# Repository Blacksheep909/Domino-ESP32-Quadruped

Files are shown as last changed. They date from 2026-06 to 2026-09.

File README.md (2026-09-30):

# Domino ESP32 Composite Quadruped

Domino is a prototype ESP32 quadruped robot built around a carbon-and-printed composite chassis, a custom 3-DoF leg mechanism, CRSF/ExpressLRS radio control, PCA9685 servo output, and CAD-to-simulation experiments.

> Work in progress: Domino is an active engineering prototype, not a finished kit. The firmware, CAD exports, PCB package, calibration notes, and simulation files are included as a project record and technical reference. The repo does not yet contain a complete step-by-step build manual, measured BOM, wiring diagram, or validated production assembly process.

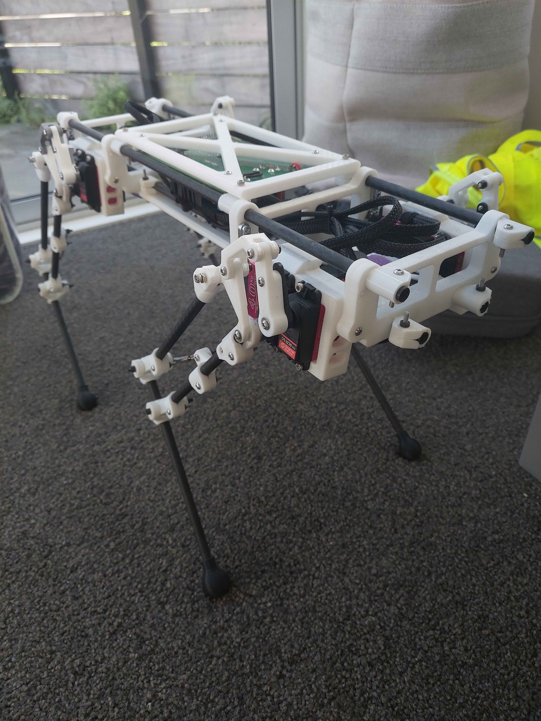
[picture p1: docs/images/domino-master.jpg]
Domino quadruped robot build


## Why This Project Matters

Domino is the successor to my earlier SpotMicro ESP32 Nitro work. The earlier project gave me a working base for servo-driven quadruped control, PCB packaging, and RC-controlled robot bring-up. Domino moves beyond that reference design into a more custom platform:

- A scratch-built mechanical layout using carbon members and 3D-printed structural parts.
- A serviceable electronics cage rather than a sealed body shell.
- Per-leg inverse kinematics for a custom 3-DoF mechanism.
- A move from iBUS-style receiver handling to custom CRSF/ExpressLRS parsing on the ESP32.
- A new Domino PCB manufacturing package based on lessons from the older SpotMicro Nitro board.
- CAD, STEP, USD, and Isaac Sim export work documenting the mechanical and simulation path.

As a portfolio project, Domino demonstrates mechanical design, embedded firmware, RC protocol work, power distribution, servo safety, calibration, and simulation constraints in one prototype hardware stack.

## Domino Quadruped Studio

**Quadruped Studio is the project's desktop engineering application.** Use it
to stand and move the CAD robot in simulation, develop gait profiles, inspect
joint travel, review calibration, record telemetry and plan routes.

**[Read the Studio guide](docs/quadruped-studio.md)** ·
**[Open the Studio source](https://github.com/Blacksheep909/Domino-ESP32-Quadruped/tree/codex/desktop-app/simulation/standalone)** ·
**[Download Studio 0.3.1 for Windows](https://github.com/Blacksheep909/Domino-ESP32-Quadruped/releases/tag/v0.3.1)**

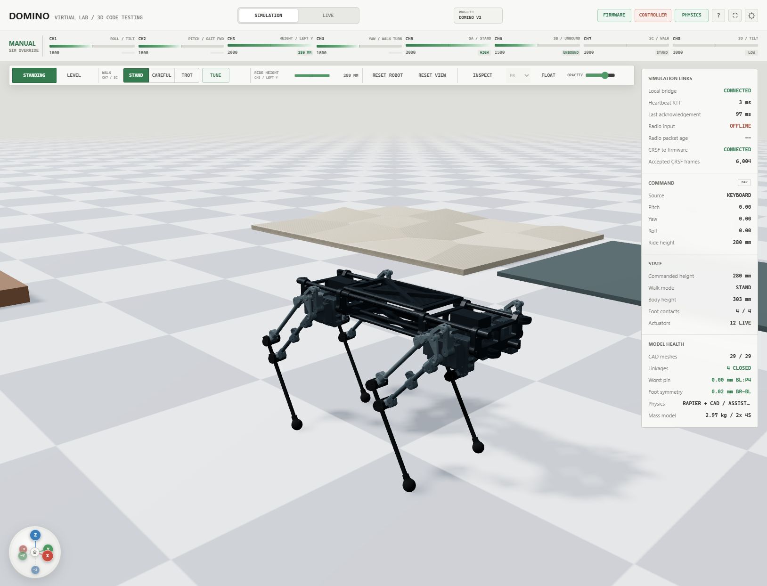
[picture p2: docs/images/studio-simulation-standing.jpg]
Domino standing on four feet in Quadruped Studio's Simulation workspace


*Captured from Studio 0.3.1. The robot is standing in the
local firmware/CAD simulation. The guide explains build availability and source
setup.*

- **Simulation:** firmware modes, actual CAD/linkage geometry, physics,
  keyboard/controllers, gait tuning and joint inspection.
- **LIVE:** comparison, data graphs, calibration, gait profiles, diagnostics
  and saved sessions through a compatible robot adapter.
- **Mission tools:** local route planning, geographic map overlays, GPS/LiDAR
  views and capability-gated vehicle controls.
- **Projects:** portable configuration files and telemetry capture/export.

## Current Status

Implemented or documented:

- [Domino Quadruped Studio](docs/quadruped-studio.md): Windows simulation and robot engineering application, with source on the `codex/desktop-app` branch.
- ESP32 DevKit firmware using PlatformIO and Arduino.
- PCA9685 output for twelve servos across four legs.
- CAD-derived inverse kinematics for hip, upper-leg, and lower-linkage angles.
- Custom CRSF/ExpressLRS receiver parser with packed-channel decoding, filtering, switch debouncing, and link-loss handling.
- Stand, stow, body tilt, ride-height preset, and experimental balance modes.
- MPU6050 IMU sampling and filtered roll/pitch state.
- Per-servo safety limits to reduce the chance of driving the mechanism into hard stops.
- STEP exports for assembly, body, and leg inspection.
- USD/USDZ exports from the Isaac Sim exploration path.
- Raw Isaac Lab URDF import smoke test documented for the generated CAD export.
- Domino PCB V1.1B Gerber package and PCB screenshots.

Still in progress:

- Full walking gait generation.
- Dynamic balance tuning.
- A complete measured BOM.
- Wiring diagrams and annotated cable-routing photos.
- Printed-part orientation, fastener, bearing, insert, and rod-length documentation.
- A validated start-to-finish public build manual.

## Where To Start

To use the desktop application, start with the [Quadruped Studio guide](docs/quadruped-studio.md).

If you are looking to build the physical robot start here:

1. [docs/control-notes.md](docs/control-notes.md) - coordinate frames, IK constants, servo mapping, and mode flow.
2. [docs/crsf.md](docs/crsf.md) - CRSF/ExpressLRS parser and receiver migration notes.
3. [docs/cad-design.md](docs/cad-design.md) - mechanical structure, STEP exports, composite cage, and simulation limitations.
4. [docs/electronics.md](docs/electronics.md) - electronics architecture, PCB evolution, and power/control notes.
5. [hardware/pcb/domino-quadruped-pcb-v1.1b](hardware/pcb/domino-quadruped-pcb-v1.1b) - Domino PCB V1.1B Gerber package.

## Mechanical Design

Each leg has three actuated degrees of freedom:

- Hip abduction/adduction.
- Upper-leg pitch.
- Lower linkage / knee motion.

The body uses a long central cage instead of a compact square chassis. This keeps wiring, receiver placement, PCB access, and servo harness routing serviceable while giving the leg modules room to move.

The lower leg behaves more like a closed-chain/four-bar mechanism than a simple open-chain robot arm. That creates useful packaging options, but it also makes firmware and simulation more demanding: servo mapping, linkage clearances, safe joint limits, and CAD-derived IK constants all need to agree.

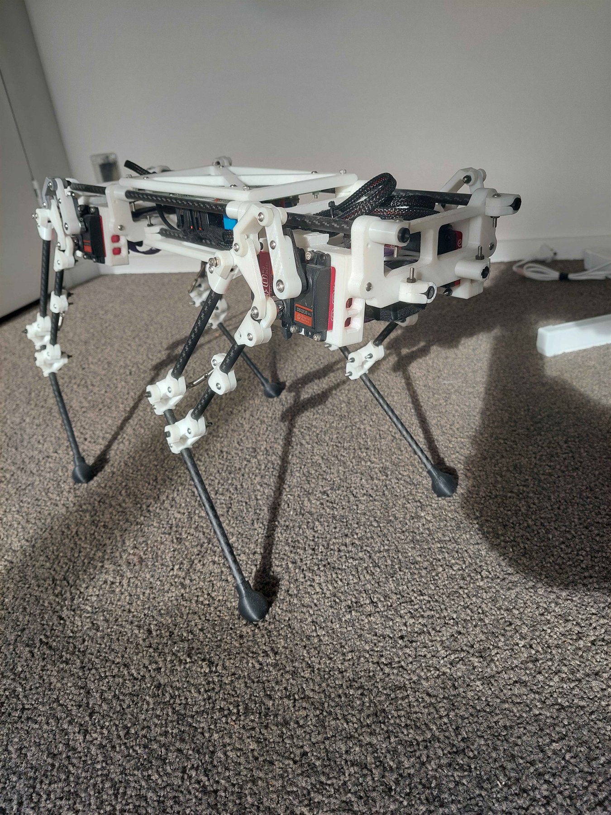
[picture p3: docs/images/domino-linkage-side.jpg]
Domino side linkage view


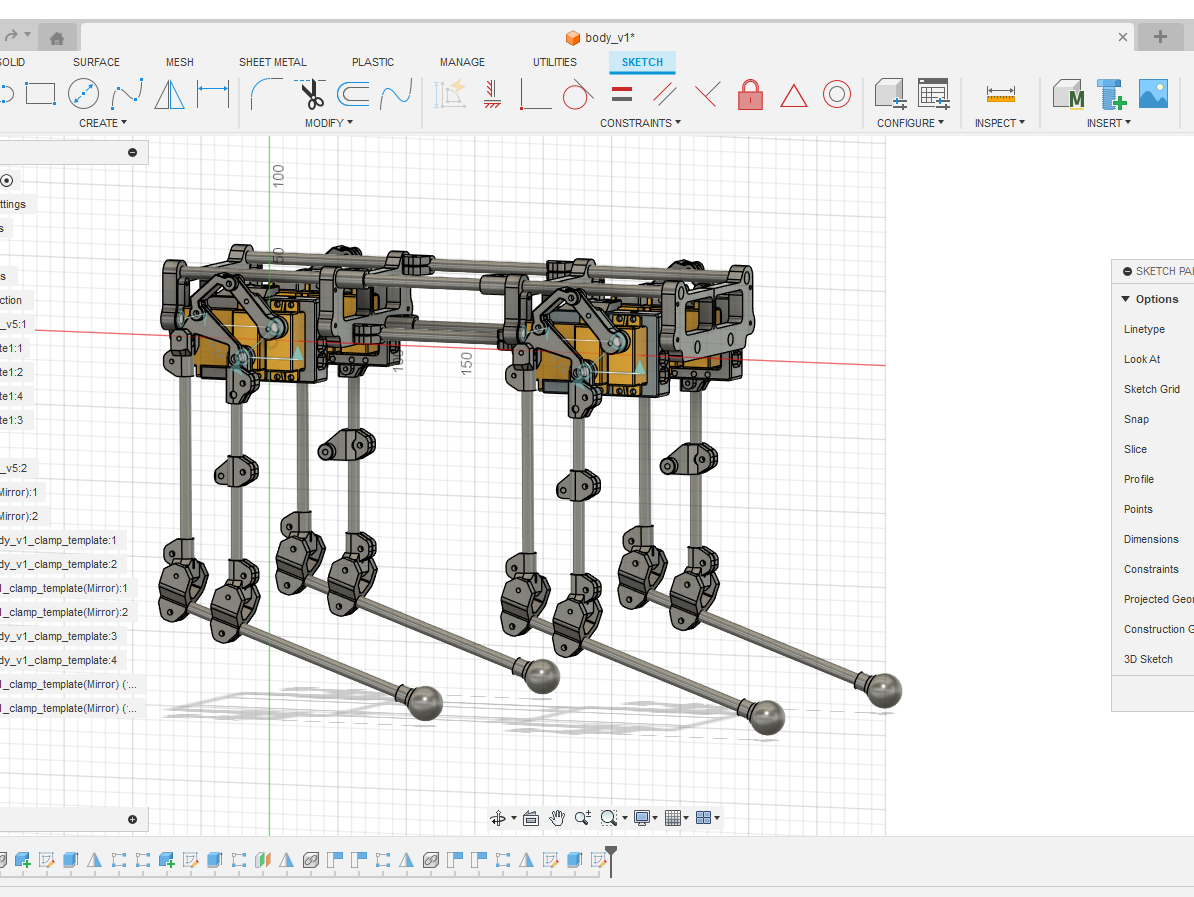
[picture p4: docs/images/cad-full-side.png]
CAD side view


The neutral CAD exports are included under [cad/step](cad/step). The mechanical write-up is in [docs/cad-design.md](docs/cad-design.md).

## Electronics

Domino began by reusing the electronics architecture from my SpotMicro ESP32 Nitro fork: ESP32 control, PCA9685 servo output, external servo power, receiver wiring, sensor headers, and utility connections gathered into a serviceable board layout.

The first Domino prototype reused the older PCB directly. Moving to CRSF/ExpressLRS did not require a full board redesign: the receiver needed suitable power, common ground, and its TX signal routed into the ESP32 serial input used by the firmware.

The newer Domino PCB V1.1B is a dedicated board package for this platform. It follows the same ESP32/PCA9685 quadruped-control concept, but adds extra headers, improves connector layout and silkscreen presentation, and addresses practical issues found while using the older board.

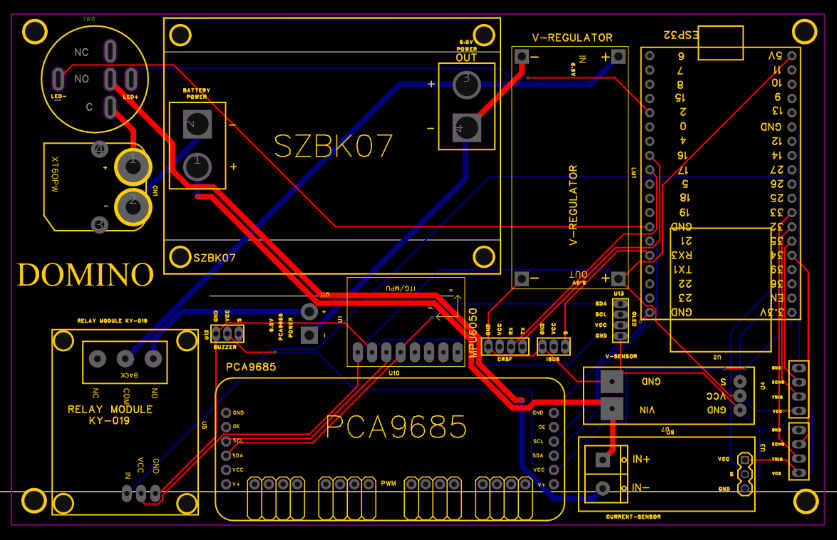
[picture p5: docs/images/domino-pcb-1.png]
Domino PCB V1.1B layout view


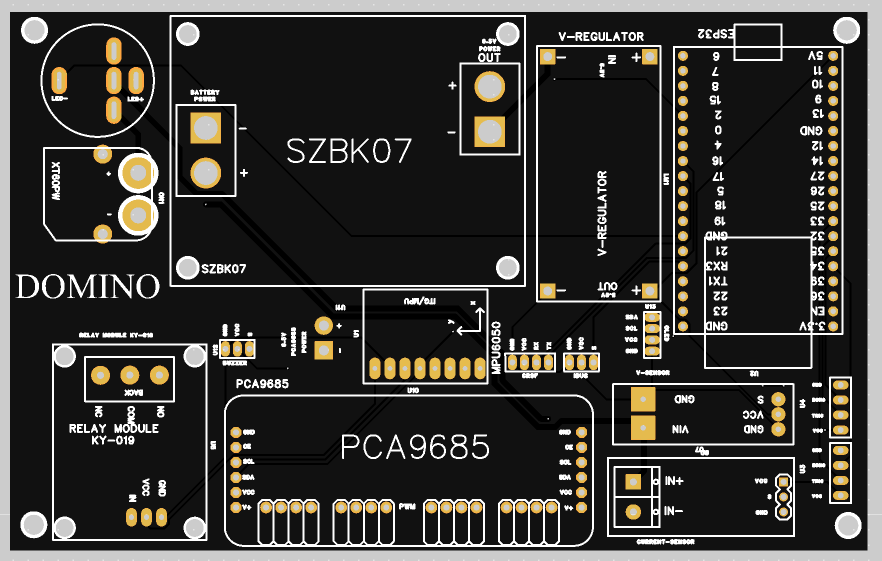
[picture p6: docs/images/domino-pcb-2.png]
Domino PCB V1.1B render


More detail is in [docs/electronics.md](docs/electronics.md).

## Firmware Architecture

The firmware is split by responsibility:

- `src/crsf.cpp` / `src/crsf.h`: CRSF frame parsing, channel unpacking, filtering, and link-health state.
- `src/ik.cpp` / `src/ik.h`: CAD-derived single-leg inverse kinematics.
- `src/leg_controller.cpp` / `src/leg_controller.h`: PCA9685 channel mapping, direction signs, trims, and servo limit enforcement.
- `src/imu.cpp` / `src/imu.h`: MPU6050 initialization, sampling, and filtered orientation state.
- `src/main.cpp`: high-level state machine, body pose model, ride height, tilt mode, balance experiment, and failsafe behavior.

High-level behavior generates body/foot pose targets, then passes them through the same IK and servo mapping path. That keeps stand, stow, tilt, balance, and future gait work tied to one low-level geometry model.

## CRSF / ExpressLRS Radio Link

One major goal of Domino was replacing simpler iBUS-style receiver handling with CRSF. CRSF is common in ExpressLRS systems and gives the robot a fast serial RC link, but it also requires correct frame synchronization, CRC validation, packed-channel decoding, filtering, and failsafe behavior.

The robot repo includes the integrated parser in `src/crsf.*` and a small example under [examples/crsf-esp32-reader](examples/crsf-esp32-reader). The reusable extraction now lives in its own repo:

- [Blacksheep909/ESP32_CRSF_Reader](https://github.com/Blacksheep909/ESP32_CRSF_Reader)

## CAD And Simulation Exports

The repo includes:

- STEP files under [cad/step](cad/step).
- USD/USDZ exports under [simulation/usd](simulation/usd).
- URDF reference export, Isaac topology report, and simulation bring-up notes under [simulation/isaac](simulation/isaac).
- CAD and simulation notes in [docs/cad-design.md](docs/cad-design.md) and [docs/simulation-notes.md](docs/simulation-notes.md).

The simulation work is exploratory. The visual model can be imported, but the real leg mechanism is closer to a closed-chain linkage than a URDF-friendly tree. A controllable simulation will need a simplified joint model or explicit constraints rather than a blind CAD import.

## Build And Bring-Up Status

The firmware can be built with PlatformIO:

```powershell
pio run
```

Upload to an ESP32 DevKit:

```powershell
pio run -t upload
```

Open the serial monitor:

```powershell
pio device monitor
```

Hardware bring-up should be done in layers: receiver first, then one servo, then one leg, then all legs on a stand. The current docs do not yet contain enough measured hardware detail to recommend building the full robot directly from the repo.

## Repository Layout

```text
.
|-- cad/
|   `-- step/                STEP exports for assembly, body, and leg modules
|-- hardware/
|   `-- pcb/                 Domino PCB Gerber package and notes
|-- simulation/
|   |-- isaac/               Isaac Sim / Isaac Lab bring-up notes and URDF topology tooling
|   |-- urdf/generated/      Generated URDF reference export
|   `-- usd/                 USD/USDZ exports for Isaac Sim experiments
|-- platformio.ini          PlatformIO build configuration
|-- src/                    Robot firmware
|-- examples/
|   `-- crsf-esp32-reader   Standalone CRSF parser demo
|-- docs/                   Design, calibration, electronics, and simulation notes
|-- include/                Project include directory
|-- lib/                    Project-local libraries
`-- test/                   Future firmware tests
```

## Related Work

This project builds on lessons from my earlier SpotMicro ESP32 fork:

- [Blacksheep909/SpotMicroESP32-Nitro-Fork](https://github.com/Blacksheep909/SpotMicroESP32-Nitro-Fork)

The earlier fork is closer to an instructional build log. Domino is a custom engineering snapshot: the firmware, CAD, PCB work, and simulation experiments are being shaped into a cleaner quadruped platform.

## Credits

Domino's mechanical direction is derived from the ESP32 quadruped robot design by [Tazer Technical](https://www.youtube.com/@TazerTechnical). Thanks to Tazer Technical for publishing the design ideas and build material that helped shape this project.

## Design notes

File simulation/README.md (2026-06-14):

# Simulation Exports

This folder contains USD-family exports from the Domino CAD-to-Isaac-Sim exploration.

> Work in progress: these files are reference exports, not a finished physics simulation. They are useful for visual import tests, scale checks, and future simulation model development.

## Files

| Path | Purpose |
| --- | --- |
| `isaac/` | Isaac Sim / Isaac Lab bring-up notes, URDF topology report, and validation tooling. |
| `urdf/generated/` | Generated URDF package from the CAD export. This is reference material, not a final training articulation. |
| `usd/Domino_Isaac_SIM.usd` | Lightweight Isaac Sim-oriented USD scene/export. |
| `usd/Domino_Quadruped.usd` | Domino quadruped USD export. |
| `usd/Domino_USD_Parts_Combined_Final.usdz` | Packaged combined USDZ export from the CAD-to-simulation trail. |

## Notes

- The visual geometry is useful.
- The generated URDF currently contains duplicate link names and loop-style child reuse, so it should not be treated as a finished Isaac articulation.
- A raw Isaac Lab URDF import smoke test has passed, but only as an import/build-artifact check. It is not a validated robot physics model.
- A clean one-leg prototype is included under `isaac/prototypes/one_leg` for the first controlled articulation tests.
- The joint hierarchy, physics properties, inertia, collisions, and actuation model still need dedicated simulation work.
- The closed-chain/four-bar leg linkage is the main reason a direct CAD import is not enough.

More context is in [../docs/simulation-notes.md](../docs/simulation-notes.md).

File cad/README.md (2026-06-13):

# CAD Exports

This folder contains neutral STEP exports for the current Domino prototype. They are included for inspection, measurement, adaptation, and CAD-to-simulation work.

> Work in progress: these are reference exports, not a complete manufacturing package. Validate clearances, servo fit, print tolerances, fastener sizes, and safe joint travel before building from them.

## STEP Files

| Path | Purpose |
| --- | --- |
| `step/assembly/Domino_URDF_Parts.step` | Full assembly-style STEP export for viewing the complete robot. |
| `step/combined/Domino_URDF_Parts_Combined.step` | Combined model export from the CAD-to-URDF trail. |
| `step/combined/Domino_URDF_Parts_Combined_Final.step` | Main combined reference export for the current documentation state. |
| `step/parts/Body.step` | Central body and electronics cage reference. |
| `step/parts/FL.step` | Front-left leg module. |
| `step/parts/FR.step` | Front-right leg module. |
| `step/parts/BL.step` | Back-left leg module. |
| `step/parts/BR.step` | Back-right leg module. |

Start with `step/combined/Domino_URDF_Parts_Combined_Final.step` to inspect the full robot. Use the individual leg files when checking mirrored geometry, servo orientation, linkage clearance, and horn travel.

More design context is in [../docs/cad-design.md](../docs/cad-design.md).

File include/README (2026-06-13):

Project-level public headers can be placed here if the firmware grows beyond the current `src/` module layout.

At the moment, Domino keeps its firmware headers beside their implementation files in `src/`:

- `src/crsf.h`
- `src/ik.h`
- `src/imu.h`
- `src/leg_controller.h`

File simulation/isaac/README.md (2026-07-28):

# Domino Isaac Sim / Isaac Lab Bring-Up

This folder is the working plan for turning Domino from CAD and firmware into a stable Isaac Sim / Isaac Lab robot. The aim is a trainable quadruped model, not just a pretty visual import.

> Current status: the raw CAD-generated URDF is not suitable as a training articulation by itself. The current Isaac Lab model reconstructs the mechanism as a stable 29-body passive-linkage system, starts in a captured bent neutral pose, exposes all 12 servo commands, and has a verified reference-conditioned four-foot linkage-swing controller. This is a mechanism demonstration, not an autonomous walking policy. Forward walking and terrain training are still in progress. The Isaac Sim and Isaac Lab runtimes are not included in this repository.

> Asset fidelity guardrail: the legacy `run_pin_linkage.py` modes are CAD-derived physics proxies with cube and sphere debug visuals. The newer CAD-linkage builder used by the policy-search and `DirectRLEnv` paths attaches the exported Domino STL link meshes to those moving physics bodies by default. Treat it as real Domino CAD visuals on simplified proxy physics, not as a final full-CAD collision model.

Visible, livestreamed, and camera-rendered proxy-only runs are blocked by default unless `--allow-proxy-visuals` is passed. This keeps the simplified cube/sphere debug scene from being mistaken for the actual Domino CAD visual model.

Visible, livestreamed, and camera-rendered multi-environment runs are also blocked by default in the CAD-linkage smoke, training, and playback scripts. Use `--num-envs 1` when checking whether the robot looks like Domino. Pass `--allow-multi-env-viewport` only when intentionally viewing cloned training batches.

## Reproduce the Current Baseline

Install Isaac Sim and Isaac Lab, then clone this repository. The CAD meshes, generated URDF package, 29-body linkage builder, 12-actuator environment, reference gait, reward configuration, launch scripts, and the pre-500-run `model_210` example policy are tracked. Isaac Sim, Isaac Lab, subsequent generated checkpoints, and local run logs are deliberately not committed.

Set the runtime locations if they are not installed at `C:\isaac-sim` and `C:\isaac-projects\IsaacLab`:

```powershell
$env:ISAAC_SIM_ROOT = "<path-to-Isaac-Sim>"
$env:ISAACLAB_ROOT = "<path-to-IsaacLab>"
```

Start a visible, single-environment PPO run using the actual Domino CAD meshes:

```powershell
powershell -ExecutionPolicy Bypass -File simulation/isaac/run-visible-domino-actual-cad-learning.ps1 `
  -NumEnvs 1 `
  -Iterations 100
```

Run 500 iterations headless across ten environments:

```powershell
powershell -ExecutionPolicy Bypass -File simulation/isaac/run-headless-domino-policy-training.ps1 `
  -NumEnvs 10 `
  -Iterations 500
```

The headless launcher resumes the newest compatible local checkpoint when one exists. Pass `-Fresh` to initialize a new actor from the tracked diagonal-trot reference, or pass `-ResumeCheckpoint <model.pt>` to choose a checkpoint explicitly. Checkpoints and reports are written below `simulation/isaac/out/`.

To train a policy from random network weights without a reference action in its observation, behavior cloning, or an imitation reward:

```powershell
powershell -ExecutionPolicy Bypass -File simulation/isaac/run-headless-domino-open-policy.ps1 `
  -NumEnvs 32 `
  -PolicyDevice cuda:0 `
  -PhysicsDevice cpu `
  -Iterations 500
```

This open-policy experiment still uses task-level reward shaping: a `0.10 m/s` forward command, measured forward displacement and velocity, diagonal stance/swing contact timing, swing-foot clearance, qualified liftoff-touchdown cycles, uprightness, and penalties for stagnation, wrong-way travel, lateral/yaw drift, contacting-foot slip, unequal completed air/contact times, abrupt actions, non-foot ground contact, and falls. The actor must discover the 12 servo commands itself; it is not given a scripted gait target. The launcher writes a checkpoint every ten iterations and applies a stricter single-policy walking gate after training.

The policy and physics devices are deliberately independent. Local July 2026 measurements on an RTX 3080 Ti found that this USD-synchronized closed-loop prototype trained faster with PPO on `cuda:0` and PhysX on `cpu`: four environments improved from `14.66` to `34.07` samples/s, ten improved from `16.98` to `48.47` samples/s, and sixteen CPU-physics environments reached `54.24` samples/s before the additional foot rewards were added. With contact slip, timing balance, and qualified-cycle rewards enabled, sixteen environments reached `50.84` samples/s and thirty-two reached `56.66` samples/s. Both device modes retained sub-`0.25 mm` maximum pin separation in the short comparison runs. The result is specific to this 29-body, 36-constraint prototype; conventional tensor-controlled tree articulations usually favor GPU PhysX.

Every new training report records `runtime.policy_device`, `runtime.physics_device`, `performance.ppo_training_wall_seconds`, and `performance.ppo_samples_per_second`. Re-run the same workload with `-PhysicsDevice cuda:0` when changing the linkage implementation, Isaac Sim version, or GPU driver rather than assuming the current result remains optimal.

The post-training gate also tracks confirmed contact-liftoff-swing-touchdown cycles per foot. A cycle is only valid when the foot remains airborne for multiple control steps, clears the terrain, travels relative to the body, returns with at least two-foot support, and stays within the configured body-tilt limit. Reports include per-foot cycle counts, rejected-cycle reasons, airborne fraction, clearance, travel, landing displacement, and single-foot domination. This rejects policies that produce large endpoint motion by throwing one leg or falling without demonstrating recoverable four-foot stepping.

Use the velocity-dominant V2 launcher for new locomotion training:

```powershell
powershell -ExecutionPolicy Bypass -File simulation/isaac/run-headless-domino-velocity-policy.ps1 `
  -NumEnvs 32 `
  -GateIterations 40 `
  -CorrectionIterations 80 `
  -TotalIterations 500
```

This launcher follows the task-first structure used by Isaac Lab's Go2, Anymal, and Spot velocity environments. Commanded velocity and directional progress dominate the locomotion reward, and stationary behavior under a nonzero command is explicitly penalized. A 40-iteration reference-scaffolded bootstrap first establishes coordinated linkage motion. The next 80 iterations emphasize measured positive-X travel while retaining a modest gait scaffold before the remaining training budget can start. Each gate also checks all-foot motion, all-linkage-drive motion, clearance, drift, tilt, resets, and pin-constraint separation. A failed gate stops the run rather than spending the full budget on a stationary or wrong-way policy. Use `run-headless-domino-open-policy.ps1` when reference actions must be completely absent.

The three gates deliberately become stricter rather than demanding a finished gait immediately. Stage one permits incomplete or unbalanced foot cycles while requiring safe motor exploration. Stage two requires at least one recoverable liftoff-touchdown cycle from every foot but tolerates an uneven early gait. The final stage requires a higher valid-cycle ratio and rejects single-foot domination.

Training episodes time out after `10 s`. A timeout is a normal state reset: PPO weights and optimizer state remain intact, and the policy continues learning from the next episode. The staged validation windows are `4.0 s`, `4.0 s`, and `4.8 s`, all shorter than the episode timeout, so a healthy policy is not rejected merely because it reached the configured time limit. Falls, unsafe body contact, excessive tilt, and missing foot recovery remain failures.

On the measured RTX 3080 Ti system, the default `32` environments and `24` control steps produce `768` transitions per PPO iteration. At `56.66` samples/s, a 500-iteration run contains `384,000` transitions and requires about `1 h 53 min` of PPO stepping. Allow roughly `2 h` total for the three CAD startups and policy gates. A from-scratch open policy may need `500-1500` iterations (`2-6 h`) before gait quality can be judged; checkpoint validation should determine when to stop, not wall-clock time alone.

On a fresh clone, the launcher automatically starts from `checkpoints/domino_actual_cad_baseline_model_210.pt`. To inspect that exact policy in a visible single-robot run before continuing PPO:

```powershell
powershell -ExecutionPolicy Bypass -File simulation/isaac/run-visible-domino-actual-cad-learning.ps1 `
  -NumEnvs 1 `
  -Iterations 1 `
  -ResumeCheckpoint simulation/isaac/checkpoints/domino_actual_cad_baseline_model_210.pt
```

This is still a work-in-progress locomotion experiment. The tracked setup demonstrates the real CAD appearance, all 12 servo channels, passive lower and upper linkage pins, reset/termination handling, and an active PPO training loop. It is not presented as a converged walking policy.

## Included Files

| Path | Purpose |
| --- | --- |
| `../usd/` | Existing USD/USDZ visual exports from the CAD-to-Isaac exploration. |
| `../urdf/generated/Domino_URDF_Parts_Combined_Final_description/` | Generated URDF package copied from the CAD export for reference and analysis. |
| `analyze-domino-urdf.ps1` | Repeatable URDF topology validator. |
| `analyze-domino-linkage-pivots.ps1` | Extracts named linkage pivot coordinates from the generated URDF for CAD-derived pin-joint tests. |
| `run-domino-urdf-import.ps1` | Parameterized Isaac Lab URDF import smoke-test helper. |
| `run-visible-domino-policy.ps1` | Visible actual-CAD playback launcher for the bent neutral pose and latest locally verified weight-transfer checkpoint. |
| `run-visible-domino-training.ps1` | Visible or headless BC/PPO launcher for the calibrated neutral, passive-linkage model. |
| `run-visible-domino-actual-cad-learning.ps1` | Current single-robot actual-CAD PPO configuration used for visual inspection. |
| `run-headless-domino-policy-training.ps1` | Clone-friendly 500-iteration headless launcher with automatic local checkpoint resume. |
| `run-headless-domino-open-policy.ps1` | From-scratch PPO launcher with no reference-action observation, behavior cloning, or imitation reward. |
| `run-headless-domino-velocity-policy.ps1` | Velocity-dominant, three-stage locomotion curriculum that rejects stationary or wrong-way policies before the long training stage. |
| `checkpoints/domino_actual_cad_baseline_model_210.pt` | Pre-500-run example policy used to reproduce or continue the current actual-CAD PPO experiment. |
| `prototypes/one_leg/` | Clean three-joint one-leg prototype for the first stable Isaac articulation. |
| `prototypes/actual_cad/` | USD audit/wrapper tools for the real Domino mesh CAD export. |
| `prototypes/pin_linkage/` | Minimal actuated pin-joint constraint prototype with generic and CAD-derived Domino linkage modes. |
| `prototypes/pin_linkage/run_domino_cad_linkage_one_foot_search.py` | Deterministic parallel search for stable single-foot unload commands using the current 12-actuator passive-linkage model. |
| `prototypes/pin_linkage/run_domino_cad_linkage_weight_transfer_search.py` | Searches stable full-body weight-transfer commands and verifies actual-CAD foot unloading for each leg. |
| `prototypes/pin_linkage/run_domino_cad_linkage_weight_transfer_cycle.py` | Runs the four verified commands as one continuous no-reset mechanics cycle. |
| `prototypes/pin_linkage/build_domino_weight_transfer_teacher.py` | Builds the tracked four-leg keyframe teacher after the continuous-cycle mechanics gate passes. |
| `config/domino_weight_transfer_cycle_teacher.json` | Current 1,360-step, 12-channel weight-transfer teacher used by BC and reference playback. |
| `prototypes/pin_linkage/run_domino_cad_linkage_teacher_order_search.py` | Evaluates all 24 four-leg swing orders in parallel against true endpoint, stability, and closure gates. |
| `prototypes/pin_linkage/build_domino_linkage_swing_teacher.py` | Builds the current verified 2,360-step linkage-swing teacher from four individually verified commands. |
| `config/domino_linkage_swing_cycle_teacher.json` | Current 12-channel teacher in rear-left, rear-right, front-right, front-left order. |
| `prototypes/pin_linkage/verify_domino_cad_linkage_reports.py` | Non-GPU verifier for local actual-CAD visual, 12-actuator, and playback report artifacts. |
| `prototypes/pin_linkage/plan_domino_cad_linkage_next_runs.py` | Generates staged PowerShell commands for the next CAD-linkage PPO/refinement experiments from verified baselines. |
| `prototypes/pin_linkage/compare_domino_cad_linkage_playbacks.py` | Compares a new CAD-linkage playback report against the retained forward, lateral-drift, and yaw baselines. |
| `reports/domino-urdf-topology.md` | Current topology report generated from the URDF export. |
| `reports/domino-linkage-pivots.md` | CAD-derived pivot report for the first lower-linkage loops. |
| `reports/domino-linkage-pivots.json` | Machine-readable pivot extraction output. |
| `reports/domino-urdf-import-smoke-test.md` | Result of the first Isaac Lab raw import smoke test. |
| `reports/domino-one-leg-import-smoke-test.md` | Result of the first clean one-leg import smoke test. |
| `reports/domino-one-leg-runtime-sweep.md` | Result of the first clean one-leg Isaac Lab articulation sweep. |
| `reports/domino-pin-linkage-runtime.md` | Results of the generic and CAD-derived actuated passive pin-linkage runtime tests. |
| `reports/domino-combined-linkage-characterization.md` | Motion characterization for the combined two-drive CAD-derived one-leg linkage. |
| `reports/domino-four-leg-linkage-runtime.md` | First all-leg CAD-derived pitch-linkage Isaac/PhysX smoke test. |
| `reports/domino-12-actuator-runtime.md` | First fixed-base all-leg scene exposing the full twelve-actuator Domino command layout. |
| `reports/domino-quadruped-runtime-sweep.md` | First clean all-leg 12-DoF Isaac Lab articulation runtime sweep. |
| `reports/domino-quadruped-contact-stand-env.md` | First floating-base contact smoke, first Domino stand `DirectRLEnv` smoke, first tiny RSL-RL PPO checkpoint smoke, and first playback smoke. |
| `reports/domino-policy-cad-linkage-contract.md` | Automated check that the clean policy action contract matches the CAD-derived shared fixed-body linkage report. |
| `reports/domino-floating-cad-linkage-contact.md` | First gravity/contact smoke for the floating CAD-derived twelve-actuator linkage scene. |
| `reports/domino-floating-cad-policy-reset.md` | First policy-style action and runtime reset smoke for the floating CAD-derived linkage scene. |
| `reports/domino-cad-linkage-direct-rl-env.md` | Isaac Lab `DirectRLEnv`, command-aware RSL-RL runs, signed-axis scripted gait search, 12-actuator BC/PPO warm starts, and current locomotion gap for the floating CAD-derived twelve-actuator linkage scene. |
| `reports/domino-split-linkage-servo-slew-status.md` | Historical split-closure and servo-slew milestone retained for engineering traceability. |

## Current Finding

The generated URDF is useful as a record of the CAD export, but it should not be imported blindly into Isaac as the final training model.

The current real visual source is `../usd/Domino_Quadruped.usd`. Direct USD inspection shows it opens as a mesh-based CAD visual export with 30 mesh prims, 0 rigid bodies, and 0 joints. That makes it useful for verifying the real Domino shape, scale, and CAD appearance, but it is not yet a trainable robot.

The raw-CAD identity audit writes to `out/cad_identity/domino_raw_cad_audit.json` and the meter-based wrapper writes to `out/cad_identity/domino_raw_cad_visual_wrapper.usda`. That wrapper is the clean visual-only file to open when checking the CAD identity before judging any physics or policy scene.

The current standalone policy-search scene is different from the raw visual export. It attaches 29 exported Domino STL meshes, totaling about 135k triangles, to 29 simplified moving physics bodies. The passive finite-link model includes both lower and upper two-pivot closure bodies instead of collapsing each loop into one joint. It reports 0 visible robot proxy cubes and 0 visible robot proxy spheres when CAD visuals are enabled, and the hidden proxy shapes are also marked as guide-purpose transparent geometry. That scene is useful for testing the twelve driven channels and closed-chain linkage behavior while showing the real Domino CAD geometry, but it should still be described as proxy physics rather than a final full-CAD collision model.

The local report verifier checks the current ignored JSON artifacts under `out/cad_identity/` before those artifacts are used as evidence. It verifies the actual-CAD visual audit, hidden proxy visuals, non-render proxy guard, 12 action channels, and the retained playback baselines. New PPO/refinement runs should also be checked with the playback comparison helper before replacing any retained baseline.

The current topology report shows:

- 37 link elements.
- 29 unique link names.
- 36 joint elements.
- 8 duplicate link-name groups.
- 8 child links with multiple incoming joints.
- 11 limited revolute joints and 25 continuous joints.

That means the file contains loop-style structure and repeated link names. Isaac/PhysX articulations need a tree structure for the articulation itself; loops can be closed separately using rigid-body joints between articulation links, but the core articulation still has to be authored cleanly. See the official PhysX articulation notes on tree structure and closing loops: [PhysX Articulations](https://nvidia-omniverse.github.io/PhysX/physx/5.4.1/docs/Articulations.html#articulation-tree-structure).

## Recommended Strategy

Do not try to make the exported CAD mates become the RL policy model directly. Build the simulator in layers:

1. **Visual model**
   - Use the USD exports for visual inspection, scale checks, orientation checks, and render/reference work.
   - Keep mesh collisions disabled or heavily simplified during early physics tests.

2. **Training articulation**
   - Create a clean 12-DoF tree articulation: hip ab/ad, upper-leg pitch, and lower/knee actuator coordinate for each leg.
   - Keep the action space tied to the twelve real servo commands rather than every passive CAD pin: four shoulder actuators plus two two-bar/four-bar linkage-drive actuators per leg.
   - Treat the upper linkage/pitch command as the second linkage-drive actuator for each leg, not as an extra passive pin or a separate reduced model.
   - Give every training joint a readable name before training; do not keep names like `Revolute 46` in the final model.

3. **Passive linkage fidelity**
   - First pass: treat the lower four-bar linkage as visual geometry attached to the controlled lower/knee body.
   - Second pass: add passive revolute pins and loop-closing rigid-body joints after a one-leg model is stable.
   - If the loop constraints fight the driven joints, keep the training model simplified and use the detailed linkage model only for validation.

4. **Isaac Lab asset config**
   - Spawn the final robot from USD using `ArticulationCfg` and `UsdFileCfg`.
   - Configure actuator groups for the twelve driven joints only.
   - Disable self-collision until basic falling, standing, and joint-limit tests are stable.
   - Use conservative solver settings and low drive gains during first motion tests.

5. **Policy path**
   - Validate one leg.
   - Validate all four legs standing on a raised fixture.
   - Train a stand/height-control task.
   - Keep velocity-command inputs explicit in the policy state, then add gait rewards and longer locomotion training after reset behavior, joint limits, and contacts are reliable.

## Commands

Run the URDF topology report:

```powershell
powershell -ExecutionPolicy Bypass -File simulation/isaac/analyze-domino-urdf.ps1
```

Run it against another exported URDF:

```powershell
powershell -ExecutionPolicy Bypass -File simulation/isaac/analyze-domino-urdf.ps1 -UrdfPath path\to\robot.urdf
```

Run a raw Isaac Lab import smoke test:

```powershell
powershell -ExecutionPolicy Bypass -File simulation/isaac/run-domino-urdf-import.ps1 `
  -IsaacLabRoot <path-to-IsaacLab> `
  -IsaacPython <path-to-isaac-python> `
  -OutputUsd <output-folder>/domino_raw_import.usd `
  -AcceptEula
```

The helper deliberately takes Isaac paths as arguments or environment variables. Do not hard-code personal workstation paths into this repository.

Run the clean one-leg prototype through the same importer:

```powershell
powershell -ExecutionPolicy Bypass -File simulation/isaac/run-domino-urdf-import.ps1 `
  -UrdfPath simulation/isaac/prototypes/one_leg/domino_one_leg_clean.urdf `
  -IsaacLabRoot <path-to-IsaacLab> `
  -IsaacPython <path-to-isaac-python> `
  -OutputUsd <output-folder>/domino_one_leg_clean.usd `
  -FixBase `
  -AcceptEula
```

Generate and import the clean all-leg quadruped prototype:

```powershell
<python> simulation/isaac/prototypes/quadruped/generate_quadruped_urdf.py

powershell -ExecutionPolicy Bypass -File simulation/isaac/run-domino-urdf-import.ps1 `
  -UrdfPath simulation/isaac/prototypes/quadruped/domino_quadruped_clean.urdf `
  -IsaacLabRoot <path-to-IsaacLab> `
  -IsaacPython <path-to-isaac-python> `
  -OutputUsd <output-folder>/domino_quadruped_clean.usd `
  -FixBase `
  -NoMergeJoints `
  -AcceptEula
```

Run the clean all-leg quadruped articulation sweep:

```powershell
<isaac-python> simulation/isaac/prototypes/quadruped/run_quadruped_sweep.py `
  --usd-path <output-folder>/domino_quadruped_clean.usd `
  --headless `
  --steps 600 `
  --report-path <output-folder>/domino_quadruped_sweep_report.json
```

Import the clean quadruped as a floating-base USD for gravity/contact tests:

```powershell
powershell -ExecutionPolicy Bypass -File simulation/isaac/run-domino-urdf-import.ps1 `
  -UrdfPath simulation/isaac/prototypes/quadruped/domino_quadruped_clean.urdf `
  -IsaacLabRoot <path-to-IsaacLab> `
  -IsaacPython <path-to-isaac-python> `
  -OutputUsd <output-folder>/domino_quadruped_clean_floating.usd `
  -NoMergeJoints `
  -AcceptEula
```

Run the floating-base gravity/contact smoke:

```powershell
<isaac-python> simulation/isaac/prototypes/quadruped/run_quadruped_contact_smoke.py `
  --usd-path <output-folder>/domino_quadruped_clean_floating.usd `
  --headless `
  --steps 1000 `
  --report-path <output-folder>/domino_quadruped_contact_report.json
```

Run the first stand-task `DirectRLEnv` smoke:

```powershell
<isaac-python> simulation/isaac/prototypes/quadruped/run_domino_stand_env_smoke.py `
  --usd-path <output-folder>/domino_quadruped_clean_floating.usd `
  --headless `
  --steps 300 `
  --num-envs 1 `
  --report-path <output-folder>/domino_stand_env_smoke_report.json
```

Run the first checkpoint-producing RSL-RL PPO smoke:

```powershell
<isaac-python> simulation/isaac/prototypes/quadruped/run_domino_stand_rsl_rl_train.py `
  --usd-path <output-folder>/domino_quadruped_clean_floating.usd `
  --headless `
  --num-envs 1 `
  --iterations 1 `
  --num-steps-per-env 8 `
  --log-root <output-folder>/domino_rsl_rl `
  --report-path <output-folder>/domino_stand_rsl_rl_report.json
```

Load and evaluate the newest RSL-RL checkpoint:

```powershell
<isaac-python> simulation/isaac/prototypes/quadruped/run_domino_stand_rsl_rl_play.py `
  --usd-path <output-folder>/domino_quadruped_clean_floating.usd `
  --headless `
  --num-envs 1 `
  --steps 250 `
  --log-root <output-folder>/domino_rsl_rl `
  --report-path <output-folder>/domino_stand_rsl_rl_play_report.json
```

Run a 16-env training-scale smoke after the one-env path is passing:

```powershell
<isaac-python> simulation/isaac/prototypes/quadruped/run_domino_stand_rsl_rl_train.py `
  --usd-path <output-folder>/domino_quadruped_clean_floating.usd `
  --headless `
  --num-envs 16 `
  --iterations 1 `
  --num-steps-per-env 8 `
  --log-root <output-folder>/domino_rsl_rl `
  --report-path <output-folder>/domino_stand_rsl_rl_train_16env_report.json
```

Extract CAD linkage pivots from the generated URDF:

```powershell
powershell -ExecutionPolicy Bypass -File simulation/isaac/analyze-domino-linkage-pivots.ps1
```

Run the CAD-derived one-joint lower-linkage test:

```powershell
<isaac-python> simulation/isaac/prototypes/pin_linkage/run_pin_linkage.py `
  --headless `
  --geometry domino-lower-triangle `
  --steps 600 `
  --drive-amplitude-deg 8 `
  --drive-frequency-hz 0.4 `
  --report-path <output-folder>/domino_lower_triangle_report.json `
  --save-usd <output-folder>/domino_lower_triangle.usd
```

Run the CAD-derived one-joint upper-linkage test:

```powershell
<isaac-python> simulation/isaac/prototypes/pin_linkage/run_pin_linkage.py `
  --headless `
  --geometry domino-upper-loop `
  --steps 600 `
  --drive-amplitude-deg 5 `
  --drive-frequency-hz 0.4 `
  --report-path <output-folder>/domino_upper_loop_report.json `
  --save-usd <output-folder>/domino_upper_loop.usd
```

Run the combined two-drive one-leg linkage test:

```powershell
<isaac-python> simulation/isaac/prototypes/pin_linkage/run_pin_linkage.py `
  --headless `
  --geometry domino-combined-leg `
  --steps 1000 `
  --fit-start-step 60 `
  --drive-amplitude-deg 2 `
  --secondary-drive-amplitude-deg 2 `
  --drive-frequency-hz 0.2 `
  --secondary-drive-frequency-hz 0.2 `
  --report-path <output-folder>/domino_combined_leg_report.json `
  --save-usd <output-folder>/domino_combined_leg.usd
```

Run the all-leg CAD-derived pitch-linkage test:

```powershell
<isaac-python> simulation/isaac/prototypes/pin_linkage/run_pin_linkage.py `
  --headless `
  --geometry domino-four-combined-legs `
  --steps 600 `
  --fit-start-step 60 `
  --drive-amplitude-deg 1 `
  --secondary-drive-amplitude-deg 1 `
  --drive-frequency-hz 0.15 `
  --secondary-drive-frequency-hz 0.15 `
  --report-path <output-folder>/domino_four_combined_legs_report.json `
  --save-usd <output-folder>/domino_four_combined_legs.usd
```

Run the all-leg independent drive calibration sweep:

```powershell
<isaac-python> simulation/isaac/prototypes/pin_linkage/run_pin_linkage.py `
  --headless `
  --geometry domino-four-combined-legs `
  --drive-schedule independent `
  --steps 3200 `
  --independent-segment-steps 400 `
  --independent-settle-steps 80 `
  --fit-start-step 0 `
  --drive-amplitude-deg 1 `
  --secondary-drive-amplitude-deg 1 `
  --drive-frequency-hz 0.15 `
  --secondary-drive-frequency-hz 0.15 `
  --report-path <output-folder>/domino_four_independent_calibration_report.json `
  --save-usd <output-folder>/domino_four_independent_calibration.usd
```

Run the fixed-base twelve-actuator scene:

```powershell
<isaac-python> simulation/isaac/prototypes/pin_linkage/run_pin_linkage.py `
  --headless `
  --geometry domino-four-12-actuators `
  --steps 600 `
  --fit-start-step 60 `
  --drive-amplitude-deg 1 `
  --secondary-drive-amplitude-deg 1 `
  --shoulder-drive-amplitude-deg 1 `
  --drive-frequency-hz 0.15 `
  --secondary-drive-frequency-hz 0.15 `
  --shoulder-drive-frequency-hz 0.15 `
  --report-path <output-folder>/domino_four_12_actuators_report.json `
  --no-print-report
```

Run the fixed-base twelve-actuator independent calibration sweep:

```powershell
<isaac-python> simulation/isaac/prototypes/pin_linkage/run_pin_linkage.py `
  --headless `
  --geometry domino-four-12-actuators `
  --drive-schedule independent `
  --steps 2400 `
  --independent-segment-steps 200 `
  --independent-settle-steps 40 `
  --fit-start-step 0 `
  --drive-amplitude-deg 1 `
  --secondary-drive-amplitude-deg 1 `
  --shoulder-drive-amplitude-deg 1 `
  --drive-frequency-hz 0.25 `
  --secondary-drive-frequency-hz 0.25 `
  --shoulder-drive-frequency-hz 0.25 `
  --report-path <output-folder>/domino_four_12_actuators_independent_report.json `
  --no-print-report
```

Run the shared-body fixed-base twelve-actuator independent calibration sweep:

```powershell
<isaac-python> simulation/isaac/prototypes/pin_linkage/run_pin_linkage.py `
  --headless `
  --geometry domino-four-12-fixed-body `
  --drive-schedule independent `
  --steps 1200 `
  --independent-segment-steps 100 `
  --independent-settle-steps 20 `
  --fit-start-step 0 `
  --drive-amplitude-deg 1 `
  --secondary-drive-amplitude-deg 1 `
  --shoulder-drive-amplitude-deg 1 `
  --drive-frequency-hz 0.5 `
  --secondary-drive-frequency-hz 0.5 `
  --shoulder-drive-frequency-hz 0.5 `
  --report-path <output-folder>/domino_four_12_fixed_body_independent_report.json `
  --no-print-report
```

Validate the policy action contract against a CAD-derived linkage JSON report:

```powershell
<python> simulation/isaac/prototypes/quadruped/check_cad_linkage_contract.py `
  --linkage-report <output-folder>/domino_four_12_fixed_body_independent_report.json `
  --urdf-path simulation/isaac/prototypes/quadruped/domino_quadruped_clean.urdf `
  --report-path <output-folder>/domino_policy_cad_contract_report.json
```

Run the floating CAD-derived twelve-actuator linkage contact smoke:

```powershell
<isaac-python> simulation/isaac/prototypes/pin_linkage/run_pin_linkage.py `
  --headless `
  --geometry domino-four-12-floating-body `
  --steps 300 `
  --drive-amplitude-deg 0 `
  --secondary-drive-amplitude-deg 0 `
  --shoulder-drive-amplitude-deg 0 `
  --drive-frequency-hz 0.5 `
  --secondary-drive-frequency-hz 0.5 `
  --shoulder-drive-frequency-hz 0.5 `
  --max-loop-closure-error-m 0.005 `
  --min-floating-root-height-m 0.02 `
  --report-path <output-folder>/domino_four_12_floating_body_report.json `
  --save-usd <output-folder>/domino_four_12_floating_body.usd `
  --no-print-report
```

Run the floating CAD-derived policy-style action/reset smoke:

```powershell
<isaac-python> simulation/isaac/prototypes/pin_linkage/run_pin_linkage.py `
  --headless `
  --geometry domino-four-12-floating-body `
  --drive-schedule policy-step `
  --steps 360 `
  --policy-action-scale-deg 0.25 `
  --policy-hold-steps 20 `
  --reset-interval-steps 120 `
  --max-post-reset-position-error-m 0.001 `
  --max-loop-closure-error-m 0.005 `
  --min-floating-root-height-m 0.02 `
  --report-path <output-folder>/domino_four_12_floating_policy_step_reset_report.json `
  --no-print-report
```

Run the floating CAD-linkage `DirectRLEnv` smoke:

```powershell
<isaac-python> simulation/isaac/prototypes/pin_linkage/run_domino_cad_linkage_env_smoke.py `
  --headless `
  --num-envs 4 `
  --steps 120 `
  --command-x-m-s 0.03 `
  --gait-frequency-hz 1.0 `
  --report-path <output-folder>/domino_cad_linkage_env_smoke_4env_command_report.json
```

Run a short command-aware RSL-RL training gate against the CAD-linkage env:

```powershell
<isaac-python> simulation/isaac/prototypes/pin_linkage/run_domino_cad_linkage_rsl_rl_train.py `
  --headless `
  --num-envs 4 `
  --iterations 10 `
  --num-steps-per-env 16 `
  --command-x-m-s 0.03 `
  --gait-frequency-hz 1.0 `
  --log-root <output-folder>/domino_rsl_rl `
  --report-path <output-folder>/domino_cad_linkage_rsl_rl_train_4env_command_10iter_report.json
```

Play back the newest CAD-linkage checkpoint:

```powershell
<isaac-python> simulation/isaac/prototypes/pin_linkage/run_domino_cad_linkage_rsl_rl_play.py `
  --headless `
  --num-envs 4 `
  --steps 240 `
  --command-x-m-s 0.03 `
  --gait-frequency-hz 1.0 `
  --log-root <output-folder>/domino_rsl_rl `
  --report-path <output-folder>/domino_cad_linkage_rsl_rl_play_4env_command_10iter_report.json
```

Verify the local actual-CAD and playback report artifacts without launching Isaac:

```powershell
<python> simulation/isaac/prototypes/pin_linkage/verify_domino_cad_linkage_reports.py
```

This verifier also checks that the top-level Isaac README, the detailed CAD-linkage DirectRLEnv report, and the actual-CAD audit report still contain the same current baseline numbers.

Generate the next recommended CAD-linkage policy experiment commands:

```powershell
<python> simulation/isaac/prototypes/pin_linkage/plan_domino_cad_linkage_next_runs.py
```

That planner was written for the pre-split-closure continuation path, so treat it as a command template rather than the current source of truth. For the current mechanics, continue from the stable `model_79.pt` / `35 deg` / `360 deg/s` servo-slew setup unless a new playback report proves a better checkpoint.

Compare a new playback report against the retained baselines:

```powershell
<python> simulation/isaac/prototypes/pin_linkage/compare_domino_cad_linkage_playbacks.py `
  --candidate <output-folder>/rsl_play_candidate.json `
  --json-summary <output-folder>/compare_candidate.json
```

## Isaac Runtime Notes

NVIDIA's current Isaac Lab import workflow recommends converting robot assets into USD and then writing an asset configuration for spawning and training. The Isaac Lab docs also call out useful URDF import settings such as fixed base selection, fixed-joint merging, joint drive configuration, and setting joint target type to `none` during import when you want to configure drives later. See:

- [Isaac Lab: Importing a New Asset](https://isaac-sim.github.io/IsaacLab/main/source/how-to/import_new_asset.html)
- [Isaac Lab: Writing an Asset Configuration](https://isaac-sim.github.io/IsaacLab/main/source/how-to/write_articulation_cfg.html)
- [Isaac Sim: Import URDF](https://docs.isaacsim.omniverse.nvidia.com/latest/importer_exporter/import_urdf.html)

## Immediate Next Milestone

This remains a work-in-progress simulation and policy-training project. The current baseline is a mechanically stable bring-up model, not a finished walking policy.

The current model uses:

- the exported Domino STL meshes for the visible robot;
- 29 simplified rigid physics bodies with passive finite lower and upper loop closures;
- all 12 real actuator channels: four 40 kg-cm shoulder servos and eight 35 kg-cm linkage servos;
- an authored 29-body neutral pose captured from a converged fixed-base linkage solve;
- CAD-derived visual-bottom foot contacts, explicit friction, realistic stall-torque caps, and a 90 deg/s target slew limit; and
- a 16-degree normalized action range around the bent neutral pose.

The current verified gates are:

| Gate | Result |
| --- | --- |
| Authored neutral, fixed base | Four bent legs, no straight-leg startup lock, approximately `1 micrometre` maximum pin error. |
| Zero-action free body, 10 seconds | No reset or detachment; about `7.2 deg` body tilt and `1.89 mm` maximum pin separation. |
| Independent 12-actuator sweep | Every actuator moves its own real CAD foot; minimum observed foot motion is about `29.5 mm`. |
| Settled free-body 12-actuator sweep | Every shoulder, lower, and upper channel moves under load in both directions with no termination; maximum pin separation stays below `3.1 mm` at the tested scale. |
| Four-leg order search | All 24 orders are evaluated in parallel. The selected rear-left, rear-right, front-right, front-left sequence was one of two orders that passed the stability, closure, drive-motion, and endpoint-motion gates. |
| Keyframed teacher playback | The 2,360-step reference completes with no reset or termination. True CAD-foot motion measured in each foot's own hip-carriage frame is `53.3-85.5 mm`; all eight linkage drives move `4.78-20.54 deg`. Maximum body tilt is `20.90 deg` and maximum pin separation is `3.73 mm`. |
| Reference-conditioned RSL-RL checkpoint | The 73-input, 12-output actor reproduces the appended verified target. Fresh checkpoint playback completes 2,360 steps with zero resets and the same endpoint, drive, tilt, and closure measurements as reference mode. A `0.0001` agreement snap executes the exact target when the policy is already within tolerance, avoiding contact-chaos divergence from floating-point copy error. |
| Visible actual-CAD inspection | A slowed single-robot playback shows the real Domino CAD, four attached bent legs, driven lower and upper links changing angle, passive closure bars remaining closed, and every foot endpoint moving. No proxy robot geometry is visible. |

The teacher and reference-conditioned checkpoint prove that the real CAD visuals, 12-channel action contract, bent neutral startup, servo limits, and closed-linkage physics run together. They do not prove autonomous locomotion learning. The current controller deliberately follows a verified mechanism trajectory; the next policy must learn stable residuals or an independent gait that produces controlled forward velocity.

Launch the current visible checkpoint:

```powershell
$env:ISAAC_SIM_ROOT = "<path-to-Isaac-Sim>"
$env:ISAACLAB_ROOT = "<path-to-IsaacLab>"
powershell -ExecutionPolicy Bypass -File simulation/isaac/run-visible-domino-policy.ps1 `
  -VisibleStartDelayS 8 `
  -VisibleStepDelayS 0.04 `
  -NoHoldOpen
```

Set `ISAAC_SIM_ROOT` and `ISAACLAB_ROOT`, or pass `-IsaacSimRoot` and `-IsaacLabRoot`. Automatic checkpoint selection accepts only the current hip-frame training artifact when either its embedded validation or a matching fresh-process validation report passed. It does not fall back to historical checkpoints. The delay options make the 47.2-second control sequence easier to inspect in the viewport.

Re-run the continuous mechanics gate and rebuild the tracked teacher after changing any of the four promoted command files:

```powershell
<isaac-python> simulation/isaac/prototypes/pin_linkage/run_domino_cad_linkage_weight_transfer_cycle.py `
  --headless `
  --leg-order 1,3,0,2 `
  --report-path simulation/isaac/out/cad_identity/next_policy/weight_transfer_context_verified_four_foot_cycle_v2.json `
  --no-print-report

<python> simulation/isaac/prototypes/pin_linkage/build_domino_weight_transfer_teacher.py
```

The builder refuses to publish a teacher unless the source continuous-cycle report passed its global mechanics gate.

Run the current lower-linkage visibility diagnostic:

```powershell
powershell -ExecutionPolicy Bypass -File simulation/isaac/run-visible-domino-policy.ps1 `
  -PolicyMode fixed `
  -TerrainType flat `
  -ActionScaleDeg 8 `
  -FixedActions "0,1,-1,0,0,0,0,0,0,0,0,0"
```

This is a mechanical one-foot unload probe, not a learned policy. It starts with the same zero-action neutral settle used by policy playback.

Run the current actual-CAD PPO experiment:

```powershell
powershell -ExecutionPolicy Bypass -File simulation/isaac/run-visible-domino-actual-cad-learning.ps1 `
  -NumEnvs 1 `
  -Iterations 100
```

The next policy pass should focus on:

- Preserve the authored neutral pose, zero-action hold, all-12-actuator sweep, and joint-separation gates.
- Turn the verified four-foot unloading sequence into an overlapping stance/swing gait with positive forward progress.
- Train velocity tracking on flat ground before introducing stairs or rough terrain.
- Keep stance/swing labels tied to settled foot trajectories so initial gravity settlement does not count as gait motion.
- Retain per-foot clearance, slip, lateral-drift, yaw, body-height, tilt, and loop-closure gates during PPO refinement.
- Keep verifying all 12 actuator channels: four shoulder hip ab/ad drives, four lower-linkage drives, and four upper pitch/linkage drives.
- Keep the detailed closed-linkage model as the mechanical validation authority, even if policy iteration later moves to a simpler tree articulation.

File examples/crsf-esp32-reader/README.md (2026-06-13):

# ESP32 CRSF Reader Example

This PlatformIO example reads CRSF / ExpressLRS RC channel frames on an ESP32 without running the full Domino robot firmware.

Use it when bringing up a receiver or checking channel mappings before connecting servos.

## Hardware

- ESP32 DevKit.
- CRSF / ExpressLRS receiver.
- Receiver TX wired to ESP32 RX pin 16.
- Common ground between receiver and ESP32.

The example initializes `Serial2` at 420000 baud and prints decoded channel values to the USB serial monitor at 115200 baud.

## Build

```powershell
pio run
```

## Monitor

```powershell
pio device monitor
```

The reusable standalone version is published here:

- [Blacksheep909/ESP32_CRSF_Reader](https://github.com/Blacksheep909/ESP32_CRSF_Reader)

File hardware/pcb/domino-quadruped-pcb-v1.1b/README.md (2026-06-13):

# Domino Quadruped PCB V1.1B

This folder contains the Gerber manufacturing package for the Domino Quadruped PCB V1.1B.

> Work in progress: this is a prototype hardware package. Inspect the Gerbers and confirm the connector pinout, power path, and mounting requirements before ordering or assembling the board.

## Files

| Path | Purpose |
| --- | --- |
| `gerbers/Gerber_Domino_Quadruped_PC_V1.1B_2026-06-13.zip` | Gerber/drill package for PCB manufacturing. |

The package contains copper layers, solder mask, silkscreen, board outline, drill files, a document layer, flying probe data, and a short ordering note.

## Design Context

This board builds on the SpotMicro ESP32 Nitro quadruped PCB concept: an ESP32-based controller board that consolidates servo control, receiver wiring, sensor connections, and power/control headers.

Domino V1.1B moves that idea toward a cleaner robot-specific board:

- Extra headers for expansion, bring-up, and receiver wiring.
- Continued ESP32/PCA9685 control architecture.
- Cleaner connector placement and silkscreen presentation.
- Better fit for the Domino electronics cage.
- Fixes for practical issues found while testing with the older board.

Domino PCB V1.1B layout view

Domino PCB V1.1B render

## Bring-Up Notes

Before installing the PCB in the robot:

1. Inspect the Gerbers in a PCB viewer.
2. Confirm board outline and mounting holes against the electronics cage.
3. Confirm receiver power, ground, and CRSF signal routing.
4. Power logic and servo rails carefully.
5. Test one servo channel before connecting all twelve servos.

See [../../../docs/electronics.md](../../../docs/electronics.md) for broader electronics notes.

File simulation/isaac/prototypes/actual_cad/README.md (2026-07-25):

# Domino Actual CAD USD Checks

This folder is for checking the real Domino CAD export separately from the simplified Isaac physics prototypes.

Use `simulation/usd/Domino_Quadruped.usd` as the current visual source of truth. It is a mesh-based USD export from the Domino CAD package. It is not an articulated Isaac Lab robot yet: it has mesh visuals, but no rigid bodies, joints, actuators, or policy-ready contact model.

Do not use the standalone pin-linkage proxy screenshots as portfolio evidence of the final robot geometry. The older pin-linkage scene uses CAD-derived pivot coordinates, but its visible bodies are cubes and foot spheres. The current CAD-linkage audit path attaches the Domino STL link package and rejects the scene if the expected `29` link meshes, `135508` visible triangles, or hidden-proxy checks do not pass.

## Audit

Run the audit with a Python that can import `pxr`:

```powershell
$env:ISAAC_SIM_ROOT = "<isaac-sim-root>"
<python> simulation/isaac/prototypes/actual_cad/domino_actual_cad_usd.py `
  --cad-usd simulation/usd/Domino_Quadruped.usd `
  --write-wrapper `
  --output-usd <output-folder>/domino_actual_cad_visual.usda `
  --json-report <output-folder>/domino_actual_cad_audit.json
```

The wrapper is visual-only. It references the real CAD USD and applies a 0.001 scale into a meter-based stage for Isaac viewing. It is intended for visual verification before the mesh is attached to the training articulation.

## Current Asset Status

| Asset | Status |
| --- | --- |
| `simulation/usd/Domino_Quadruped.usd` | Real mesh CAD visual export; opens as 30 mesh prims, 0 rigid bodies, and 0 joints. |
| `cad/step/combined/Domino_URDF_Parts_Combined_Final.step` | Combined CAD reference export for geometry inspection and re-export. |
| `simulation/urdf/generated/Domino_URDF_Parts_Combined_Final_description/` | Generated URDF/STL export with named links and pivots; useful for topology and linkage mapping. |
| `simulation/isaac/out/cad_floating/domino_four_12_floating_body.usd` | Older generated proxy physics scene; cube/sphere visuals and PhysX revolute constraints. |
| `simulation/isaac/prototypes/pin_linkage/audit_domino_cad_linkage_visuals.py` | Current no-render audit for the runtime scene that attaches Domino STL mesh parts to the CAD-derived linkage proxy, verifies the known Domino triangle total, and verifies proxy visuals are hidden. |

## Next Work

The current simulator path attaches Domino STL mesh parts to the already tested twelve-actuator linkage bodies. Physics is still simplified at first, but the visible model is no longer the cube/sphere proxy when the actual-CAD path is enabled. The next work is to improve visual inspection renders, then decide whether the final training asset stays on this closed-linkage proxy or moves to a cleaner 12-DoF articulation validated against it.

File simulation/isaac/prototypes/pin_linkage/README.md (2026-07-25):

# Domino Pin-Linkage Prototype

This prototype is the next physics gate after the simplified one-leg articulation.

The goal is to prove that a small closed linkage can run in Isaac/PhysX with:

- One actuated revolute input pin.
- Passive revolute pins for the other linkage members.
- A loop-closing revolute pin.
- No contacts or gravity in the first pass.

This started as a controlled generic four-bar test, then gained CAD-derived one-joint, one-leg, all-leg pitch-linkage, fixed-base twelve-actuator, shared-body twelve-actuator, and floating shared-body Domino linkage modes.

Important visual-fidelity note: the standalone `run_pin_linkage.py` modes are CAD-derived physics proxies. The pivots and actuator layout come from the Domino CAD/URDF export, but those standalone visuals are simple cubes and foot spheres.

The CAD-linkage builder used by the standalone policy-search runner and `DirectRLEnv` path now attaches the exported Domino STL link meshes to the moving proxy rigid bodies by default. In that path, the physics remains a controllable proxy linkage, but the visible robot is real Domino CAD geometry from the URDF mesh export. Use `--disable-actual-cad-visuals` only for proxy debugging, and pair it with `--allow-proxy-visuals` for non-headless runs.

If the viewport shows several dark blocky robots, that is a multi-env/debug view and is not the CAD identity check. Use the single-robot actual-CAD audit and preview output for visual verification.

Visible standalone proxy runs are blocked by default. Pass `--headless` for normal standalone physics gates. Pass `--allow-proxy-visuals` only when deliberately debugging the simplified cube/sphere linkage.

## Runtime Test

Run the generic linkage with the Isaac Lab Python environment:

```powershell
<isaac-python> simulation/isaac/prototypes/pin_linkage/run_pin_linkage.py `
  --headless `
  --geometry generic-four-bar `
  --steps 240 `
  --report-path <output-folder>/pin_linkage_report.json
```

Run the CAD-derived Domino lower-linkage loop:

```powershell
<isaac-python> simulation/isaac/prototypes/pin_linkage/run_pin_linkage.py `
  --headless `
  --geometry domino-lower-triangle `
  --steps 600 `
  --drive-amplitude-deg 8 `
  --drive-frequency-hz 0.4 `
  --report-path <output-folder>/domino_lower_triangle_report.json `
  --save-usd <output-folder>/domino_lower_triangle.usd
```

Run the CAD-derived Domino upper linkage loop:

```powershell
<isaac-python> simulation/isaac/prototypes/pin_linkage/run_pin_linkage.py `
  --headless `
  --geometry domino-upper-loop `
  --steps 600 `
  --drive-amplitude-deg 5 `
  --drive-frequency-hz 0.4 `
  --report-path <output-folder>/domino_upper_loop_report.json `
  --save-usd <output-folder>/domino_upper_loop.usd
```

The script authors the linkage directly into the current Isaac stage, applies sinusoidal targets to the driven input joints, steps physics, and reports body state, loop-closure drift, drive target ranges, body pitch ranges, relative linkage angles, tracked pivot motion, and an optional local linear calibration fit.

Runtime status: the current passive finite-closure model starts from a captured 29-body bent neutral pose instead of asking PhysX to assemble the loops under gravity. A fixed-base sweep has exercised all 12 drives independently; every channel moves the corresponding real CAD foot and the smallest measured foot displacement is about `29.5 mm`. A settled free-body sweep confirms that all 12 channels move under load in both directions without a termination, and a ten-second zero-action hold completes without a reset or detached leg. Stable weight-transfer commands are now verified for all four legs in one continuous no-reset cycle. A replay-trained BC policy reproduces that cycle while unloading every actual-CAD foot. It remains a weight-transfer policy rather than a walking policy. See [`../../README.md`](../../README.md) for the current measured gates and limitations.

The earlier split-closure and servo-slew milestone is retained in [`../../reports/domino-split-linkage-servo-slew-status.md`](../../reports/domino-split-linkage-servo-slew-status.md) for engineering traceability; it is not the current model description.

Motion-characterization status: the combined one-leg mechanism is stable and has a first local linear calibration fit from drive targets to measured linkage-output proxies. The all-leg pitch scene has an independent one-drive-at-a-time calibration sweep that gives a full-rank local fit for all eight pitch drives. The twelve-actuator scenes add the four shoulder hip ab/ad drives and give full-rank local fits across all twelve actuator inputs. The current strongest gate is `domino-four-12-fixed-body`, where all four shoulder joints attach to one shared kinematic body reference. These fits are useful engineering data, but they are not yet the final policy action/state mapping. See [`../../reports/domino-combined-linkage-characterization.md`](../../reports/domino-combined-linkage-characterization.md), [`../../reports/domino-four-leg-linkage-runtime.md`](../../reports/domino-four-leg-linkage-runtime.md), and [`../../reports/domino-12-actuator-runtime.md`](../../reports/domino-12-actuator-runtime.md).

Run the combined CAD-derived one-leg mechanism:

```powershell
<isaac-python> simulation/isaac/prototypes/pin_linkage/run_pin_linkage.py `
  --headless `
  --geometry domino-combined-leg `
  --steps 1000 `
  --fit-start-step 60 `
  --drive-amplitude-deg 2 `
  --secondary-drive-amplitude-deg 2 `
  --drive-frequency-hz 0.2 `
  --secondary-drive-frequency-hz 0.2 `
  --report-path <output-folder>/domino_combined_leg_report.json `
  --save-usd <output-folder>/domino_combined_leg.usd
```

Run the all-leg CAD-derived pitch-linkage scene:

```powershell
<isaac-python> simulation/isaac/prototypes/pin_linkage/run_pin_linkage.py `
  --headless `
  --geometry domino-four-combined-legs `
  --steps 600 `
  --fit-start-step 60 `
  --drive-amplitude-deg 1 `
  --secondary-drive-amplitude-deg 1 `
  --drive-frequency-hz 0.15 `
  --secondary-drive-frequency-hz 0.15 `
  --report-path <output-folder>/domino_four_combined_legs_report.json `
  --save-usd <output-folder>/domino_four_combined_legs.usd
```

Run the all-leg independent drive calibration sweep:

```powershell
<isaac-python> simulation/isaac/prototypes/pin_linkage/run_pin_linkage.py `
  --headless `
  --geometry domino-four-combined-legs `
  --drive-schedule independent `
  --steps 3200 `
  --independent-segment-steps 400 `
  --independent-settle-steps 80 `
  --fit-start-step 0 `
  --drive-amplitude-deg 1 `
  --secondary-drive-amplitude-deg 1 `
  --drive-frequency-hz 0.15 `
  --secondary-drive-frequency-hz 0.15 `
  --report-path <output-folder>/domino_four_independent_calibration_report.json `
  --save-usd <output-folder>/domino_four_independent_calibration.usd
```

Run the fixed-base twelve-actuator scene:

```powershell
<isaac-python> simulation/isaac/prototypes/pin_linkage/run_pin_linkage.py `
  --headless `
  --geometry domino-four-12-actuators `
  --steps 600 `
  --fit-start-step 60 `
  --drive-amplitude-deg 1 `
  --secondary-drive-amplitude-deg 1 `
  --shoulder-drive-amplitude-deg 1 `
  --drive-frequency-hz 0.15 `
  --secondary-drive-frequency-hz 0.15 `
  --shoulder-drive-frequency-hz 0.15 `
  --report-path <output-folder>/domino_four_12_actuators_report.json `
  --no-print-report
```

Run the fixed-base twelve-actuator independent sweep:

```powershell
<isaac-python> simulation/isaac/prototypes/pin_linkage/run_pin_linkage.py `
  --headless `
  --geometry domino-four-12-actuators `
  --drive-schedule independent `
  --steps 2400 `
  --independent-segment-steps 200 `
  --independent-settle-steps 40 `
  --fit-start-step 0 `
  --drive-amplitude-deg 1 `
  --secondary-drive-amplitude-deg 1 `
  --shoulder-drive-amplitude-deg 1 `
  --drive-frequency-hz 0.25 `
  --secondary-drive-frequency-hz 0.25 `
  --shoulder-drive-frequency-hz 0.25 `
  --report-path <output-folder>/domino_four_12_actuators_independent_report.json `
  --no-print-report
```

Run the shared-body fixed-base twelve-actuator independent sweep:

```powershell
<isaac-python> simulation/isaac/prototypes/pin_linkage/run_pin_linkage.py `
  --headless `
  --geometry domino-four-12-fixed-body `
  --drive-schedule independent `
  --steps 1200 `
  --independent-segment-steps 100 `
  --independent-settle-steps 20 `
  --fit-start-step 0 `
  --drive-amplitude-deg 1 `
  --secondary-drive-amplitude-deg 1 `
  --shoulder-drive-amplitude-deg 1 `
  --drive-frequency-hz 0.5 `
  --secondary-drive-frequency-hz 0.5 `
  --shoulder-drive-frequency-hz 0.5 `
  --report-path <output-folder>/domino_four_12_fixed_body_independent_report.json `
  --no-print-report
```

Run the floating shared-body twelve-actuator contact smoke:

```powershell
<isaac-python> simulation/isaac/prototypes/pin_linkage/run_pin_linkage.py `
  --headless `
  --geometry domino-four-12-floating-body `
  --steps 300 `
  --drive-amplitude-deg 0 `
  --secondary-drive-amplitude-deg 0 `
  --shoulder-drive-amplitude-deg 0 `
  --drive-frequency-hz 0.5 `
  --secondary-drive-frequency-hz 0.5 `
  --shoulder-drive-frequency-hz 0.5 `
  --max-loop-closure-error-m 0.005 `
  --min-floating-root-height-m 0.02 `
  --report-path <output-folder>/domino_four_12_floating_body_report.json `
  --save-usd <output-folder>/domino_four_12_floating_body.usd `
  --no-print-report
```

Run the floating shared-body policy-style action/reset smoke:

```powershell
<isaac-python> simulation/isaac/prototypes/pin_linkage/run_pin_linkage.py `
  --headless `
  --geometry domino-four-12-floating-body `
  --drive-schedule policy-step `
  --steps 360 `
  --policy-action-scale-deg 0.25 `
  --policy-hold-steps 20 `
  --reset-interval-steps 120 `
  --max-post-reset-position-error-m 0.001 `
  --max-loop-closure-error-m 0.005 `
  --min-floating-root-height-m 0.02 `
  --report-path <output-folder>/domino_four_12_floating_policy_step_reset_report.json `
  --no-print-report
```

Run the floating CAD-linkage `DirectRLEnv` smoke:

```powershell
<isaac-python> simulation/isaac/prototypes/pin_linkage/run_domino_cad_linkage_env_smoke.py `
  --headless `
  --num-envs 4 `
  --steps 120 `
  --command-x-m-s 0.03 `
  --gait-frequency-hz 1.0 `
  --report-path <output-folder>/domino_cad_linkage_env_smoke_4env_command_report.json
```

By default this smoke attaches actual Domino CAD STL visuals to the simulated linkage. To deliberately render the simplified proxy instead, add `--disable-actual-cad-visuals --allow-proxy-visuals`.

Audit the runtime visual scene without launching the renderer:

```powershell
$env:ISAAC_SIM_ROOT = "<isaac-sim-root>" # ISAAC_PATH from Isaac's python wrapper also works
<isaac-python> simulation/isaac/prototypes/pin_linkage/audit_domino_cad_linkage_visuals.py `
  --output-usd <output-folder>/domino_actual_cad_linkage_visual_audit.usda `
  --json-report <output-folder>/domino_actual_cad_linkage_visual_audit.json
```

The audit fails if the source CAD USD contains proxy cubes/spheres, if the runtime scene is missing Domino STL mesh parts, if the visible STL triangle total is not the known Domino export total of `135508`, or if the robot proxy cubes/spheres are visible.

Run a short command-aware RSL-RL training gate against the CAD-linkage env:

```powershell
<isaac-python> simulation/isaac/prototypes/pin_linkage/run_domino_cad_linkage_rsl_rl_train.py `
  --headless `
  --num-envs 4 `
  --iterations 10 `
  --num-steps-per-env 16 `
  --command-x-m-s 0.03 `
  --gait-frequency-hz 1.0 `
  --log-root <output-folder>/domino_rsl_rl `
  --report-path <output-folder>/domino_cad_linkage_rsl_rl_train_4env_command_10iter_report.json
```

Run a locomotion reward/foot-lift smoke with larger clamped drive authority:

```powershell
<isaac-python> simulation/isaac/prototypes/pin_linkage/run_domino_cad_linkage_env_smoke.py `
  --headless `
  --num-envs 4 `
  --steps 120 `
  --action-amplitude 0.5 `
  --command-x-m-s 0.08 `
  --action-scale-deg 30.0 `
  --command-progress-reward-scale 20.0 `
  --command-velocity-tracking-reward-scale 4.0 `
  --gait-contact-reward-scale 1.0 `
  --stance-contact-reward-scale 0.5 `
  --swing-contact-penalty-scale -1.5 `
  --foot-clearance-reward-scale 1.0 `
  --foot-contact-reward-scale 0.0 `
  --episode-length-s 6.0 `
  --report-path <output-folder>/domino_cad_linkage_env_smoke_4env_scale30_foot_height_report.json
```

Search scripted 12-actuator reference gaits:

```powershell
<isaac-python> simulation/isaac/prototypes/pin_linkage/run_domino_cad_linkage_gait_search.py `
  --headless `
  --candidate-count 16 `
  --steps 240 `
  --seed 7 `
  --action-scale-deg 30.0 `
  --command-x-m-s 0.08 `
  --gait-frequency-hz 1.0 `
  --episode-length-s 6.0 `
  --save-best-candidate <output-folder>/domino_cad_linkage_best_gait_seed7.json `
  --report-path <output-folder>/domino_cad_linkage_gait_search_seed7_16_report.json
```

The gait-search action rows are built as three commands per leg in the shared order: shoulder hip ab/ad, lower linkage drive, and upper linkage/pitch drive. That is 4 shoulder actuators plus 8 linkage-drive actuators, for 12 total. The runner validates the action tensor shape before stepping the environment and records the exact action names in its JSON report.

> Historical result: the original scripted search produced a `36.5 mm` forward-displacement candidate and a lower-drift behavior-cloning baseline. Those runs predate the current calibrated-neutral passive-linkage model and are retained for comparison only; they are not the current locomotion baseline.

Verify, build, and inspect the current four-leg weight-transfer teacher:

```powershell
<isaac-python> simulation/isaac/prototypes/pin_linkage/run_domino_cad_linkage_weight_transfer_cycle.py `
  --headless `
  --leg-order 1,3,0,2 `
  --report-path simulation/isaac/out/cad_identity/next_policy/weight_transfer_context_verified_four_foot_cycle_v2.json `
  --no-print-report

<python> simulation/isaac/prototypes/pin_linkage/build_domino_weight_transfer_teacher.py

<isaac-python> simulation/isaac/prototypes/pin_linkage/run_domino_cad_linkage_rsl_rl_play.py `
  --policy-mode reference `
  --num-envs 1 `
  --steps 1360 `
  --startup-zero-steps 120 `
  --reference-gait-candidate simulation/isaac/config/domino_weight_transfer_cycle_teacher.json `
  --include-reference-actions-in-observation `
  --action-scale-deg 8 `
  --servo-target-rate-limit-deg-s 90 `
  --episode-length-s 40 `
  --foot-collision-mode actual-cad-visual-bottom `
  --closure-model passive `
  --terrain-type flat `
  --report-path <output-folder>/domino_weight_transfer_reference_playback.json
```

The teacher contains 1,360 keyframed 12-channel actions in the verified front-left, rear-right, front-right, rear-left order. The environment maps the matching leg to swing state during each segment and keeps the other three in stance. This sequence is the mechanics reference used for replay BC; it is not itself a learned policy.

Play back the newest CAD-linkage checkpoint:

```powershell
<isaac-python> simulation/isaac/prototypes/pin_linkage/run_domino_cad_linkage_rsl_rl_play.py `
  --headless `
  --num-envs 4 `
  --steps 240 `
  --command-x-m-s 0.03 `
  --gait-frequency-hz 1.0 `
  --log-root <output-folder>/domino_rsl_rl `
  --report-path <output-folder>/domino_cad_linkage_rsl_rl_play_4env_command_10iter_report.json
```

Generate the next recommended PPO/refinement commands from the verified baselines:

```powershell
<python> simulation/isaac/prototypes/pin_linkage/plan_domino_cad_linkage_next_runs.py
```

This historical planner continues from the older 70-degree `model_20.pt` PPO checkpoint and writes train/play artifacts under `simulation/isaac/out/cad_identity/next_policy/`. Its commands target the superseded direct-closure model; review and update the generated arguments before using them with the calibrated-neutral passive-linkage environment. The comparison tool remains useful for archived reports:

```powershell
<python> simulation/isaac/prototypes/pin_linkage/compare_domino_cad_linkage_playbacks.py `
  --candidate <output-folder>/rsl_play_candidate.json `
  --json-summary <output-folder>/compare_candidate.json
```

The first generated `-6 deg` yaw/lateral PPO refinement stayed upright and kept actual Domino CAD visuals enabled, but it did not replace the retained BC baselines: playback averaged about `50.6 mm` forward displacement, about `8.6 mm` lateral displacement, and about `0.162 rad` final heading drift.

A later 70-degree heading refinement produced a more useful historical checkpoint curve while keeping the same actual-CAD visual guard. `model_20.pt` was the then-balanced candidate at about `66.4 mm` forward displacement, `-0.5 mm` lateral displacement, and `0.283 rad` final heading drift. Later checkpoints pushed forward displacement higher, up to about `82.5 mm` at `model_79.pt`, but the final checkpoint also increased lateral and heading error. A stricter straightness continuation from `model_20.pt` reduced yaw to about `0.232-0.248 rad`, but forward displacement fell to about `60.3-62.5 mm`. A softer forward-preserving continuation reached about `68.9 mm` forward and `2.5 mm` lateral displacement, but yaw increased to about `0.311 rad`. Treat all of these direct-closure checkpoints as archived diagnostics rather than current walking policies.

## CAD-Derived Modes

The `domino-lower-triangle`, `domino-upper-loop`, `domino-combined-leg`, `domino-four-combined-legs`, `domino-four-12-actuators`, `domino-four-12-fixed-body`, and `domino-four-12-floating-body` modes use pivots extracted by [`../../analyze-domino-linkage-pivots.ps1`](../../analyze-domino-linkage-pivots.ps1).

Lower triangle:

| Role | URDF joint |
| --- | --- |
| Driven input | `Revolute 59` |
| Passive stack pin | `Revolute 43` |
| Passive coupler pin | `Revolute 33` |
| Loop closure | `Revolute 25` / `Revolute 26` |

Upper loop:

| Role | URDF joint |
| --- | --- |
| Held lower input | `Revolute 59` / `Revolute 43` |
| Driven input | `Revolute 58` |
| Passive coupler pin | `Revolute 32` |
| Loop closure | `Revolute 51` |

Combined leg:

| Role | URDF joint |
| --- | --- |
| Lower driven input | `Revolute 59` |
| Upper driven input | `Revolute 58` |
| Shared coupler | `Revolute 43`, `Revolute 33`, `Revolute 32` |
| Lower loop closure | `Revolute 25` / `Revolute 26` |
| Upper loop closure | `Revolute 32` / `Revolute 51` direct closure |

All-leg scene:

| Leg module | Shoulder hip ab/ad | Lower driven input | Upper driven input | Lower loop closure | Upper loop closure |
| --- | --- | --- | --- | --- | --- |
| `dom_p_4_1` | `Revolute 1` | `Revolute 59` | `Revolute 58` | `Revolute 25` / `Revolute 26` | `Revolute 32` / `Revolute 51` |
| `dom_p_12_1` | `Revolute 2` | `Revolute 46` | `Revolute 55` | `Revolute 23` / `Revolute 24` | `Revolute 29` / `Revolute 50` |
| `dom_p_25_1` | `Revolute 3` | `Revolute 47` | `Revolute 56` | `Revolute 21` / `Revolute 22` | `Revolute 34` / `Revolute 54` |
| `dom_p_21_1` | `Revolute 4` | `Revolute 48` | `Revolute 57` | `Revolute 27` / `Revolute 28` | `Revolute 31` / `Revolute 53` |

## Drive Schedules

`--drive-schedule phased-sine` is the default smoke test. All drives move together with phase offsets, which is useful for constraint stability but not enough for independent calibration because the input matrix is rank deficient.

`--drive-schedule independent` moves one drive at a time while the other drives hold their center positions. Use this mode when fitting the local relationship between the commanded inputs and measured output proxies. In the twelve-actuator modes, one independent cycle covers all twelve real actuator channels: four shoulders, four lower linkage drives, and four upper linkage/pitch drives. That is one shoulder actuator plus two two-bar/four-bar linkage-drive actuators per leg.

`--drive-schedule policy-step` applies bounded normalized action vectors to the same twelve actuator channels and holds each vector for `--policy-hold-steps`. Use this mode with `--reset-interval-steps` to check reset/action mechanics before changing the Isaac Lab CAD-linkage training wrapper.

The JSON report includes a named `action_space` and an `action_contract` block with the exact action index order. The script validates that twelve-actuator CAD scenes expose all four shoulders and all eight linkage-drive inputs before simulation starts. It also checks generated drive targets against the modeled joint limits by default; use `--disable-drive-limit-checks` only for deliberate stress tests.

## What Passing Means

Passing means the isolated one-actuator passive-pin loops, a simplified two-drive combined leg, a fixed-base all-leg pitch-linkage scene, a fixed-base twelve-actuator scene, and a shared fixed-body twelve-actuator scene can run without non-finite state or obvious constraint explosion. The calibration fits mean the combined one-leg case, the all-leg pitch independent sweep, and the twelve-actuator independent sweeps have repeatable local relationships between commanded drive targets and measured linkage-output proxies over the tested range.

The floating shared-body smoke adds gravity, a static ground box, and four simple spherical contact proxies at the CAD lower-closure points. Passing that test means the CAD-derived linkage can hold a static supported pose under gravity while keeping the loop-closure error finite.

The policy-step reset smoke proves the same floating scene accepts policy-shaped twelve-channel commands and can reset all CAD-linkage rigid bodies back to their initial poses during runtime.

The CAD-linkage `DirectRLEnv` and RSL-RL gates prove the floating shared-body scene can be stepped through Isaac Lab's RL API, can emit a 12-output actor, can write checkpoints, and can play back checkpoints without fall terminations over the tested horizon. The base observation has 61 values. The current teacher-conditioned policy appends the 12 reference actions, giving the actor a 73-value observation.

It does **not** mean Domino has a finished walking policy. The current replay-trained checkpoint starts bent, keeps all four legs attached, moves every lower endpoint, and raises every actual-CAD foot during its assigned swing segment. The next policy milestone is an overlapping stance/swing sequence that produces controlled forward velocity. Stair and rough-terrain training come after that flat-ground gait passes the existing stability, contact, and closure gates.

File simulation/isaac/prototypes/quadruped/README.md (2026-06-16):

# Domino Clean Quadruped Prototype

This folder contains the first clean all-leg Domino training-articulation prototype.

The raw CAD URDF is still kept as reference, but it is not used directly for training because it contains duplicate link names and closed linkage loops. This prototype takes the CAD-derived actuator layout and emits a simple tree articulation that Isaac Lab can import:

- Four shoulder hip ab/ad joints.
- Four lower linkage command joints.
- Four upper pitch command joints.
- CAD-derived hip locations, shoulder axis signs, and joint limits.

That gives the real 12-servo Domino command layout: one shoulder actuator plus two pitch/linkage-drive actuators per leg. The Isaac Lab config treats this order as a hard contract and the runtime checks fail if any of the 12 imported actuator joints are missing or reordered.

Per leg, the commanded actuator layout is:

- `shoulder_ab_ad`: hip/shoulder abduction-adduction.
- `lower_linkage`: one drive channel for the two-bar/four-bar leg linkage.
- `upper_pitch`: the second drive channel for the two-bar/four-bar leg linkage.

Across four legs this gives 4 shoulder actuators and 8 linkage-drive actuators, 12 total.

The passive two-bar/four-bar linkage is not physically closed in this asset yet. That detail is currently validated in the pin-linkage prototype and should be added back as a separate fixed-base constraint gate before attempting a high-fidelity floating robot.

## Generate URDF

```powershell
<python> simulation/isaac/prototypes/quadruped/generate_quadruped_urdf.py
```

## Import

```powershell
powershell -ExecutionPolicy Bypass -File simulation/isaac/run-domino-urdf-import.ps1 `
  -UrdfPath simulation/isaac/prototypes/quadruped/domino_quadruped_clean.urdf `
  -IsaacLabRoot <path-to-IsaacLab> `
  -IsaacPython <path-to-isaac-python> `
  -OutputUsd <output-folder>/domino_quadruped_clean.usd `
  -FixBase `
  -NoMergeJoints `
  -AcceptEula
```

## Runtime Sweep

```powershell
<isaac-python> simulation/isaac/prototypes/quadruped/run_quadruped_sweep.py `
  --usd-path <output-folder>/domino_quadruped_clean.usd `
  --headless `
  --steps 600 `
  --report-path <output-folder>/domino_quadruped_sweep_report.json
```

This sweep is a fixed-base articulation check. Passing means the imported USD exposes the full twelve-action Domino order, grouped as four shoulders, four lower-linkage drives, and four upper-pitch drives, and can accept conservative joint-position targets without non-finite state or joint-limit violations. It is not the final policy-training environment yet.

Runtime status: this prototype has passed a fixed-base Isaac Lab articulation sweep. See [`../../reports/domino-quadruped-runtime-sweep.md`](../../reports/domino-quadruped-runtime-sweep.md).

## Floating Contact Smoke

Import without `-FixBase`, then run:

```powershell
<isaac-python> simulation/isaac/prototypes/quadruped/run_quadruped_contact_smoke.py `
  --usd-path <output-folder>/domino_quadruped_clean_floating.usd `
  --headless `
  --steps 1000 `
  --report-path <output-folder>/domino_quadruped_contact_report.json
```

This uses a simple static ground-box collider because the local Isaac ground-plane helper currently fails to resolve its internal collision prim. Runtime status: passed. See [`../../reports/domino-quadruped-contact-stand-env.md`](../../reports/domino-quadruped-contact-stand-env.md).

## Stand Environment Smoke

Run the first `DirectRLEnv` wrapper:

```powershell
<isaac-python> simulation/isaac/prototypes/quadruped/run_domino_stand_env_smoke.py `
  --usd-path <output-folder>/domino_quadruped_clean_floating.usd `
  --headless `
  --steps 300 `
  --num-envs 1 `
  --report-path <output-folder>/domino_stand_env_smoke_report.json
```

`DominoStandEnv` has 12 actions, 49 policy observations, reset logic, rewards, and termination checks. The 12 actions are the four shoulder ab/ad actuators plus two linkage-drive actuators on each leg: `lower_linkage` and `upper_pitch`. The latest observation layout adds four foot-contact flags to the original base, joint, and action terms.

## RSL-RL PPO Smoke

Run a tiny checkpoint-producing training smoke:

```powershell
<isaac-python> simulation/isaac/prototypes/quadruped/run_domino_stand_rsl_rl_train.py `
  --usd-path <output-folder>/domino_quadruped_clean_floating.usd `
  --headless `
  --num-envs 1 `
  --iterations 1 `
  --num-steps-per-env 8 `
  --log-root <output-folder>/domino_rsl_rl `
  --report-path <output-folder>/domino_stand_rsl_rl_report.json
```

Runtime status: passed. The smoke produced a 49-input actor/critic, a 12-output actor, and a `model_0.pt` checkpoint. This is only a training-path proof, not a useful walking policy yet.

## RSL-RL Playback Smoke

Load the newest checkpoint under the log root and step it in a fresh env:

```powershell
<isaac-python> simulation/isaac/prototypes/quadruped/run_domino_stand_rsl_rl_play.py `
  --usd-path <output-folder>/domino_quadruped_clean_floating.usd `
  --headless `
  --num-envs 1 `
  --steps 250 `
  --log-root <output-folder>/domino_rsl_rl `
  --report-path <output-folder>/domino_stand_rsl_rl_play_report.json
```

Runtime status: passed. The playback smoke loaded `model_0.pt`, emitted finite 12-channel actions, and completed one stand-task episode horizon without a fall termination.

## Parallel Training Smoke

The stand env sizes its static ground from the cloned-env grid, so it can run small parallel RSL-RL tests without cloned robots starting off the ground plate.

Example 16-env training-scale smoke:

```powershell
<isaac-python> simulation/isaac/prototypes/quadruped/run_domino_stand_rsl_rl_train.py `
  --usd-path <output-folder>/domino_quadruped_clean_floating.usd `
  --headless `
  --num-envs 16 `
  --iterations 1 `
  --num-steps-per-env 8 `
  --log-root <output-folder>/domino_rsl_rl `
  --report-path <output-folder>/domino_stand_rsl_rl_train_16env_report.json
```

Example 16-env playback:

```powershell
<isaac-python> simulation/isaac/prototypes/quadruped/run_domino_stand_rsl_rl_play.py `
  --usd-path <output-folder>/domino_quadruped_clean_floating.usd `
  --headless `
  --num-envs 16 `
  --steps 250 `
  --log-root <output-folder>/domino_rsl_rl `
  --report-path <output-folder>/domino_stand_rsl_rl_play_16env_report.json
```

Runtime status: passed. The contact-aware 16-env smoke used a 10 m ground box, completed a 128-timestep PPO rollout/update with 49 policy observations, wrote a checkpoint, then replayed that checkpoint for one episode horizon across all 16 envs. All 16 done events were expected timeouts, not fall terminations.

The remaining CAD-fidelity gap is important: this training env still uses the clean tree articulation. The CAD-derived passive linkage loops now pass fixed-base, shared-body, first floating gravity/contact, and policy-style reset/action smokes in the pin-linkage prototype, but they are not yet merged into this cloned policy-training articulation.

## CAD Linkage Contract Check

After generating a `domino-four-12-fixed-body` JSON report from the pin-linkage prototype, verify the clean policy action contract against it:

```powershell
<python> simulation/isaac/prototypes/quadruped/check_cad_linkage_contract.py `
  --linkage-report <output-folder>/domino_four_12_fixed_body_independent_report.json `
  --urdf-path simulation/isaac/prototypes/quadruped/domino_quadruped_clean.urdf `
  --report-path <output-folder>/domino_policy_cad_contract_report.json
```

Runtime status: passed. The checker validates the twelve action names/order, CAD-derived roles, policy limits, clean URDF limits, default joint positions, per-leg actuator layout, and full-rank CAD linkage calibration. See [`../../reports/domino-policy-cad-linkage-contract.md`](../../reports/domino-policy-cad-linkage-contract.md).

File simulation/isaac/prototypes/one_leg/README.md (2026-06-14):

# Domino One-Leg Isaac Prototype

This folder contains a deliberately simplified one-leg model for Isaac Sim / Isaac Lab bring-up.

The aim is not to preserve every CAD mate. The aim is to create a clean, controllable articulation that matches the firmware abstraction:

- `hip_ab_ad`: hip abduction/adduction.
- `upper_pitch`: upper leg pitch.
- `lower_linkage`: effective lower-leg / knee linkage command.

The passive four-bar linkage is represented as simplified visual geometry only. Loop-closing constraints should be added later, after this driven model imports, resets, and sweeps through its limits without instability.

## Files

| File | Purpose |
| --- | --- |
| `domino_one_leg_clean.urdf` | Minimal three-joint URDF with primitive geometry, simple inertials, joint limits, and no mesh dependencies. |
| `domino_one_leg_cfg.py` | Isaac Lab `ArticulationCfg` template for the imported one-leg USD. |

## Geometry Basis

The prototype uses the current firmware geometry constants:

| Quantity | Value |
| --- | ---: |
| Upper virtual link length | `0.160 m` |
| Lower virtual link length | `0.153 m` |
| Hip lateral offset | `0.038 m` |
| Hip vertical offset | `0.021 m` |

The firmware leg frame uses +Z downward. Isaac scenes normally use +Z upward, so this prototype places the foot below the hip along negative Z in the URDF.

## Import

From the repository root:

```powershell
powershell -ExecutionPolicy Bypass -File simulation/isaac/run-domino-urdf-import.ps1 `
  -UrdfPath simulation/isaac/prototypes/one_leg/domino_one_leg_clean.urdf `
  -IsaacLabRoot <path-to-IsaacLab> `
  -IsaacPython <path-to-isaac-python> `
  -OutputUsd <output-folder>/domino_one_leg_clean.usd `
  -FixBase `
  -AcceptEula
```

Then point `DOMINO_ONE_LEG_USD` at the generated USD before using `domino_one_leg_cfg.py` inside an Isaac Lab script.

Import status: this prototype has passed a first Isaac Lab URDF-to-USD smoke test. See [`../../reports/domino-one-leg-import-smoke-test.md`](../../reports/domino-one-leg-import-smoke-test.md).

## Runtime Sweep

After importing the fixed-base USD, run the articulation sweep:

```powershell
<isaac-python> simulation/isaac/prototypes/one_leg/run_one_leg_sweep.py `
  --usd-path <output-folder>/domino_one_leg_clean.usd `
  --headless `
  --steps 600 `
  --report-path <output-folder>/domino_one_leg_sweep_report.json
```

This spawns the imported one-leg USD as an Isaac Lab `Articulation`, verifies the three expected joint names, applies sinusoidal joint-position targets inside the soft limits, and fails on non-finite joint or root state.

The script force-exits after writing the report by default because `SimulationApp.close()` can hang on some Windows Isaac Sim installs. Use `--graceful-close` only when debugging shutdown behavior.

Runtime status: the simplified fixed-base leg has passed a headless Isaac Lab articulation sweep. See [`../../reports/domino-one-leg-runtime-sweep.md`](../../reports/domino-one-leg-runtime-sweep.md).

## Next Checks

1. Import the URDF to USD.
2. Spawn the USD in Isaac Lab with `domino_one_leg_cfg.py`.
3. Sweep `hip_ab_ad`, `upper_pitch`, and `lower_linkage` through conservative ranges.
4. Confirm axes move in the same sense as the firmware commands.
5. Add visual linkage detail or passive constraints only after the three driven joints are stable.

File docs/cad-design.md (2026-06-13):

# CAD And Mechanical Design

Domino is built around a carbon-and-printed composite structure, modular 3-DoF legs, and a serviceable central electronics cage. The CAD files are included because the mechanical design is a major part of the project: firmware geometry, servo calibration, electronics packaging, and simulation work all depend on the physical layout.

> Work in progress: these CAD exports are prototype reference files. They are suitable for inspection, measurement, and adaptation, but they are not yet a complete manufacturing package. Servo fit, fastener sizes, rod lengths, print tolerances, and safe joint travel still need builder-side validation.

## Included STEP Exports

The STEP files live under [`cad/step`](../cad/step).

| File | Role |
| --- | --- |
| [`cad/step/assembly/Domino_URDF_Parts.step`](../cad/step/assembly/Domino_URDF_Parts.step) | Full assembly export for viewing the complete robot. |
| [`cad/step/combined/Domino_URDF_Parts_Combined.step`](../cad/step/combined/Domino_URDF_Parts_Combined.step) | Combined geometry export from the CAD-to-URDF trail. |
| [`cad/step/combined/Domino_URDF_Parts_Combined_Final.step`](../cad/step/combined/Domino_URDF_Parts_Combined_Final.step) | Main combined reference export for the current documentation state. |
| [`cad/step/parts/Body.step`](../cad/step/parts/Body.step) | Central body and electronics cage. |
| [`cad/step/parts/FL.step`](../cad/step/parts/FL.step) | Front-left leg module. |
| [`cad/step/parts/FR.step`](../cad/step/parts/FR.step) | Front-right leg module. |
| [`cad/step/parts/BL.step`](../cad/step/parts/BL.step) | Back-left leg module. |
| [`cad/step/parts/BR.step`](../cad/step/parts/BR.step) | Back-right leg module. |

Start with the combined final file to inspect the whole robot. Use the individual body and leg files when checking mirrored geometry, servo orientation, linkage clearance, and packaging changes.

## Design Intent

The design leaves the structure, electronics, wiring, and linkages visible and serviceable. That makes the robot easier to debug and makes the engineering decisions readable in photos, CAD views, and code review.

The body acts as an electronics spine. Printed plates and braces locate the electronics bay and leg modules, while carbon members carry longer span loads without making the body bulky.

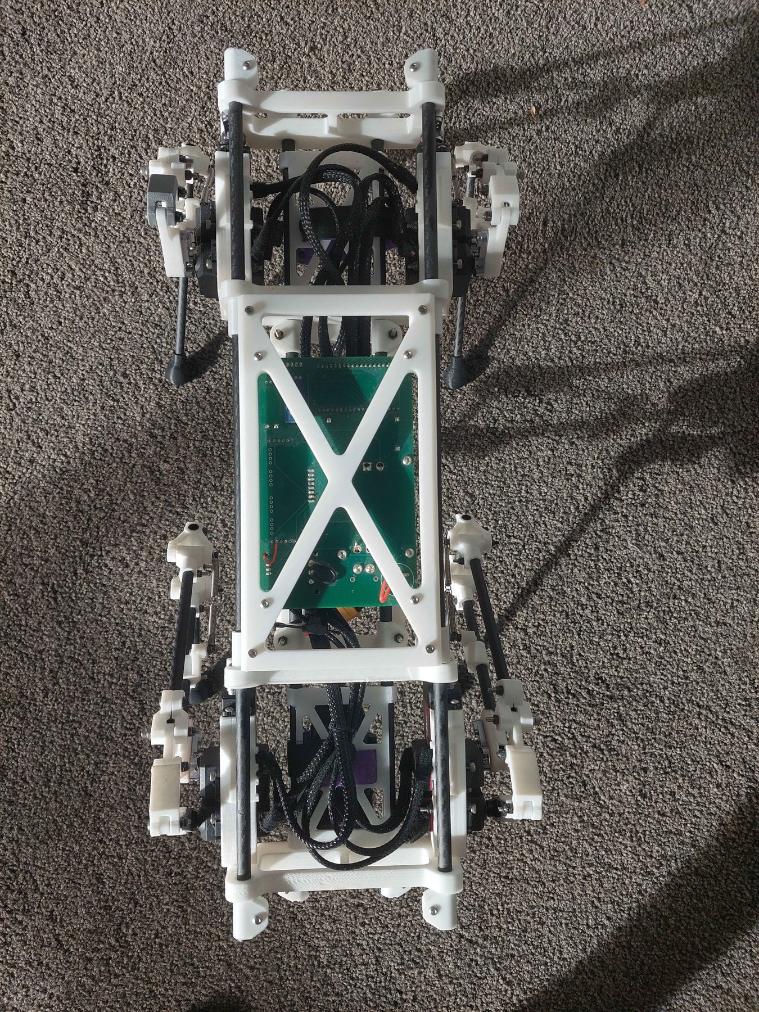
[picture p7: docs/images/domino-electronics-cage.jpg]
Domino electronics cage


Each leg module provides:

- Hip abduction/adduction.
- Upper-leg pitch.
- Lower linkage / knee motion.

The lower mechanism is closer to a closed-chain/four-bar linkage than a simple serial arm. That affects the whole project: the CAD must provide clearance, the firmware must use the effective leg geometry, and simulation must either approximate or explicitly constrain the closed loop.

Domino side linkage view

## Composite Cage Structure

The central chassis can be treated as a composite cage:

- Printed parts define mounting surfaces, pivots, and electronics placement.
- Carbon rods/tubes provide stiffness across longer spans.
- The PCB, receiver, regulator, and servo harnessing remain accessible.
- Leg motion remains the dominant packaging constraint rather than body width.
- Body, leg, electronics, and carbon-member changes can be iterated separately.

This modularity is why the repo includes separate body and corner-leg STEP files instead of only a single monolithic assembly.

## Firmware Relationship

CAD changes can affect firmware behavior. Changes to link length, servo horn clocking, pivot location, or body width may require updates to:

- IK reachability in [`src/ik.cpp`](../src/ik.cpp).
- Servo direction and trim values in [`src/leg_controller.cpp`](../src/leg_controller.cpp).
- Per-servo safety limits.
- Stand, stow, ride-height, and tilt poses in [`src/main.cpp`](../src/main.cpp).

After a mechanical change, repeat the bring-up and calibration process. Do not assume the existing trim values or safety limits still protect the mechanism.

## Simulation And URDF Notes

The current STEP exports came from the same CAD export trail used for the URDF and Isaac Sim experiments. USD/USDZ exports are included under [`simulation/usd`](../simulation/usd).

The visual CAD import is useful, but it is not automatically a physically correct simulation. URDF-style robots are usually tree-structured, while Domino's lower leg linkage behaves more like a closed chain.

A useful simulation path is:

1. Validate one simplified leg first.
2. Match joint axes and limits to the CAD.
3. Add rods and linkage members as visual geometry where needed.
4. Add closed-chain constraints only if the simulator workflow supports them cleanly.
5. Scale to the full quadruped after one leg is controllable.

More detail is in [simulation-notes.md](simulation-notes.md).

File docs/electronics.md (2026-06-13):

# Electronics Notes

Domino's electronics are built around a practical goal: reduce wiring uncertainty in a twelve-servo robot while keeping the control hardware accessible for testing, repair, and iteration.

> Work in progress: this document describes the current electronics architecture and PCB package. It is not yet a full wiring diagram or production assembly guide.

## System Blocks

The current architecture includes:

- ESP32 DevKit controller.
- PCA9685 16-channel PWM servo driver.
- CRSF/ExpressLRS receiver input.
- External high-current servo power path.
- Regulated logic power.
- MPU6050 IMU.
- Servo harnessing for twelve 270-degree servos.
- Utility headers for sensors, receiver wiring, and bring-up experiments.

## Evolution From SpotMicro Nitro

The first Domino prototype reused the PCB direction from my earlier SpotMicro ESP32 Nitro build. That board collected the ESP32, PCA9685, power distribution, receiver wiring, and sensor/utility connections into one serviceable layout.

For the initial Domino prototype, the CRSF/ExpressLRS receiver change was a wiring-level modification rather than a full PCB redesign. The receiver needed appropriate power, common ground, and its TX signal routed to the ESP32 serial RX input used by the firmware.

That approach let the robot validate the CRSF firmware and mechanical packaging before committing to a new PCB revision.

## Electronics Cage

Domino uses a central electronics cage rather than a sealed body shell. The cage is a functional mechanical feature, not decoration.

Design intent:

- Keep the PCB visible and serviceable.
- Protect the electronics inside the body rails.
- Provide predictable cable routing for twelve servo leads.
- Keep receiver and ESP32 access practical during testing.
- Prevent the body from becoming wider than the leg motion envelope.

Domino electronics cage

This packaging choice matters because quadrupeds become wiring projects very quickly. A central cage makes failures easier to inspect and makes the robot's design decisions visible in photos and reviews.

## Power And Servo Control

The ESP32 controls behavior and state. The PCA9685 generates servo PWM. Servo power must be supplied separately from the ESP32 USB/logic power path.

Bring-up checks:

- ESP32, receiver, PCA9685, and servo power must share ground.
- Servo voltage must match the selected servos.
- The regulator/BEC must handle realistic servo current, including stall events.
- One servo channel should be tested before all twelve servos are connected.
- Mechanical horn alignment should be corrected physically before relying on software trims.

## Domino PCB V1.1B

Domino now includes a dedicated PCB manufacturing package:

- [hardware/pcb/domino-quadruped-pcb-v1.1b](../hardware/pcb/domino-quadruped-pcb-v1.1b)

This board is closely related to the SpotMicro ESP32 Nitro quadruped PCB concept, but it is cleaner and more targeted for Domino. It keeps the ESP32/PCA9685 controller direction while adding extra headers, improving connector placement and silkscreen readability, and addressing practical issues found while using the older board.

Domino PCB V1.1B layout view

Domino PCB V1.1B render

The PCB package is included as a prototype manufacturing reference. Before ordering or assembling it, inspect the Gerbers, confirm the connector pinout against the firmware, and bring the board up one subsystem at a time.

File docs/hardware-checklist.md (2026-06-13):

# Hardware Planning Checklist

> Work in progress: this is a planning checklist, not a verified bill of materials. Exact fastener sizes, printed-part settings, rod lengths, battery choice, regulator rating, and final wiring diagrams still need to be documented.

## Core Electronics

- ESP32 DevKit-style board.
- PCA9685 16-channel PWM servo driver or Domino PCB V1.1B.
- CRSF / ExpressLRS receiver.
- MPU6050 IMU.
- High-current servo regulator or BEC.
- Battery suitable for the selected servos and regulator.
- Common-ground wiring between servo power, ESP32, receiver, and PCA9685.

## Actuation

- Twelve 270-degree servos.
- Servo horns that can be mechanically re-clocked.
- Servo extensions or harnessing for four legs.
- Hardware for pivots, rods, inserts, and printed joints.

## Mechanical Structure

- 3D-printed body plates, clamps, pivot parts, and linkage parts.
- Carbon rods or tubes for the leg links and body rails.
- Feet or end caps for the rods.
- Springs or linkage hardware if using the same assisted linkage direction.

## Tools

- 3D printer or access to printed parts.
- Soldering iron.
- Multimeter.
- Small screwdrivers or hex drivers.
- Calipers.
- Bench power supply, if available.
- USB cable for the ESP32.
- Stand or jig that lets all four legs move without supporting the robot's weight.

## Decisions Still Required For A Rebuild

- Exact ESP32 board pinout.
- Receiver wiring and CRSF serial pin assignment.
- Servo model and safe operating voltage.
- Regulator/BEC current capacity.
- Servo horn orientation.
- Printed-part material and tolerances.
- Fastener, insert, bearing, and rod dimensions.
- Whether the builder is copying Domino directly or adapting the firmware to different geometry.

## Safety Notes

Servos can draw high current and move suddenly. Bring the system up in layers:

1. ESP32 on USB only.
2. CRSF receiver only.
3. One servo.
4. One complete leg.
5. All legs with the robot lifted safely.
6. Floor testing only after stand/stow behavior is predictable.

Do not hold the robot by a moving linkage while testing mode transitions.

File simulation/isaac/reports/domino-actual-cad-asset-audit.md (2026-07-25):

# Domino Actual CAD Asset Audit

This audit separates the real Domino CAD visual export from the simplified Isaac physics prototypes.

## Source Of Truth

Use `simulation/usd/Domino_Quadruped.usd` as the current visual source of truth for Domino. It opens as a mesh-based CAD visual export:

| Check | Result |
| --- | --- |
| Default prim | `/Domino_USD_Parts_Combined_Final` |
| Stage units | `metersPerUnit = 0.001` |
| Up axis | `Z` |
| Mesh prims | `30` |
| Cube prims | `0` |
| Sphere prims | `0` |
| Rigid bodies | `0` |
| Joints | `0` |

This confirms it is actual CAD visual geometry, not the proxy linkage scene. It is not yet a policy-ready Isaac robot because it has no articulation, rigid-body setup, contact model, actuator config, or closed-loop linkage constraints.

The policy bring-up path now uses exported Domino mesh parts as visuals on top of the controllable CAD-derived linkage proxy. The current moving-scene audit attaches `29` Domino STL meshes with `135508` total triangles to the proxy rigid bodies, keeps `12` actuator drives, authors `28` revolute joints, and hides the proxy robot cubes/spheres so the rendered robot is not the blocky debug scaffold. Those proxy collision/debug shapes are also marked as guide-purpose transparent geometry when actual CAD visuals are enabled.

The runtime visual audit now fails if the scene only exposes proxy geometry, a partial CAD attachment, or a different STL package with the wrong Domino triangle total:

| Check | Result |
| --- | --- |
| Runtime visual fidelity | `actual_cad_stl_visuals_on_proxy_physics` |
| Expected Domino STL parts | `29` |
| Runtime Domino STL mesh prims | `29` |
| Visible Domino STL mesh prims | `29` |
| Visible Domino STL triangles | `135508` |
| Visible proxy cubes | `0` |
| Visible proxy spheres | `0` |
| Proxy visual render guard | `guide-purpose + transparent` |
| Runtime visual bounds | about `0.611 m x 0.238 m x 0.391 m` |

This still means the physics model is a proxy linkage with CAD-derived pivots and hidden proxy collision bodies. It does **not** mean the raw CAD USD has become a clean closed-chain articulation. For visual checks and portfolio screenshots, use a single robot scene and the actual-CAD audit path; do not use multi-env training screenshots, proxy-only debug renders, or renderer-crash screenshots as evidence of the Domino geometry. If the viewport shows several dark blocky robots, assume it is a training/debug view until this audit confirms the visible STL mesh count and hidden proxy counts.

## Proxy Scene Contrast

The current floating linkage training scene generated under `simulation/isaac/out/cad_floating/` is a physics proxy:

| Check | Result |
| --- | --- |
| Mesh prims | `0` |
| Cube prims | `22` |
| Sphere prims | `4` |
| Rigid bodies | `21` |
| PhysX revolute joints | `28` |

That proxy is still useful because it tests the twelve actuator channels and closed-loop pin constraints without relying on the broken raw URDF topology. It should not be used for visual evidence of the finished Domino CAD.

## Isaac Visual Path

Use `simulation/isaac/prototypes/actual_cad/domino_actual_cad_usd.py` to audit the real CAD export and create a meter-based visual wrapper:

```powershell
$env:ISAAC_SIM_ROOT = "<isaac-sim-root>" # ISAAC_PATH from Isaac's python wrapper also works
<python> simulation/isaac/prototypes/actual_cad/domino_actual_cad_usd.py `
  --cad-usd simulation/usd/Domino_Quadruped.usd `
  --write-wrapper `
  --output-usd <output-folder>/domino_actual_cad_visual.usda `
  --json-report <output-folder>/domino_actual_cad_audit.json
```

The wrapper is visual-only. The runtime `DirectRLEnv` path now attaches the exported Domino STL mesh groups to the simplified linkage bodies. The remaining work is not visual identity; it is improving the closed-chain physics/contact model and training policy quality while keeping the proxy colliders and loop constraints stable.

Use `simulation/isaac/prototypes/pin_linkage/audit_domino_cad_linkage_visuals.py` to audit the runtime CAD-linkage visual attachment without launching the renderer:

```powershell
$env:ISAAC_SIM_ROOT = "<isaac-sim-root>" # ISAAC_PATH from Isaac's python wrapper also works
<python> simulation/isaac/prototypes/pin_linkage/audit_domino_cad_linkage_visuals.py `
  --output-usd <output-folder>/domino_actual_cad_linkage_visual_audit.usda `
  --json-report <output-folder>/domino_actual_cad_linkage_visual_audit.json
```

That audit builds the current linkage scene in memory, checks the real CAD USD source, verifies the expected Domino STL parts and triangle total are visible, and verifies the proxy cubes/spheres are hidden and marked as non-render debug geometry.

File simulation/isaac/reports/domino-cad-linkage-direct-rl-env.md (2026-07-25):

# Domino CAD Linkage DirectRLEnv Training Gate

> Historical report: these results describe the superseded direct-closure model. The current calibrated-neutral passive-linkage status and measured gates are maintained in [`../README.md`](../README.md).

This report records the Isaac Lab `DirectRLEnv` wrapper, RSL-RL training, and checkpoint playback gates for the floating Domino linkage scene.

Status: **passed for manually authored CAD-derived linkage proxy `DirectRLEnv` environments, command-aware RSL-RL checkpointing/playback, scripted foot-lift smoke tests, signed-axis 12-actuator gait search, stable 12-actuator reference-action warm starts, and short PPO continuation replays on the Domino 12-actuator action contract**.

This is still a bring-up gate, not a trained walking result. The physics model remains a controllable CAD-derived proxy linkage, but the current `DirectRLEnv` builder attaches the exported Domino STL link meshes to the moving rigid bodies by default. The visible robot is therefore actual Domino CAD geometry, while the collision/contact model is still simplified.

Historical training metrics in this report were produced before the STL visual overlay existed, so those older JSON reports show `proxy_cubes_and_foot_spheres` and `actual_cad_visual=false`. The current builder audit now reports `actual_cad_stl_visuals_on_proxy_physics` and `actual_cad_visual=true`.

If an Isaac viewport shows several dark, blocky robots, treat it as a debug/training view until this audit passes. The CAD identity gate is the single-robot actual-CAD audit: source CAD mesh prims, visible runtime STL mesh count, visible STL triangle total, and zero visible robot proxy cubes/spheres.

## Historical Verified Gate

This one-robot CAD identity gate was rerun on 2026-06-28. The local RSL-RL dependency stack used Isaac's bundled CUDA Torch runtime; the overlay dependency that mattered was `tensordict==0.8.3`, because newer `tensordict` wheels could crash against the bundled Torch version used for these runs.
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

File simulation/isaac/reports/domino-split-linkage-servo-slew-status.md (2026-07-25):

# Historical Split-Linkage and Servo-Slew Status

> Historical note: this report records an earlier proxy-model milestone. The current passive finite-link, actual-CAD contact, authored-neutral-pose baseline is documented in [`../README.md`](../README.md).

This report captures the current Isaac Lab bring-up state after the closed-linkage and servo-command fixes. Paths below are repository-relative.

## Current Model

The active Domino simulation path is the CAD-linkage `DirectRLEnv`:

- Actual Domino STL visuals are attached to proxy rigid bodies.
- The visible robot uses 29 exported STL meshes and about 135k triangles.
- Proxy cubes and spheres are hidden when CAD visuals are enabled.
- The physics model is still proxy physics, not final full-CAD collision.
- The current proxy closes the lower and upper linkage loops directly between the neighboring moving links; it no longer creates extra one-pivot closure rigid bodies.
- The action space is still the real 12-servo layout: four shoulder hip ab/ad servos, four lower-linkage drives, and four upper pitch/linkage drives.
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

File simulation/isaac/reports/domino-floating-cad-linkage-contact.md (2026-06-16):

# Domino Floating CAD Linkage Contact Smoke

This report records the first gravity/contact smoke for the CAD-derived twelve-actuator pin-linkage scene.

Status: **passed for a floating shared-body CAD-linkage smoke with gravity and simple foot contact proxies**.

## What Changed
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

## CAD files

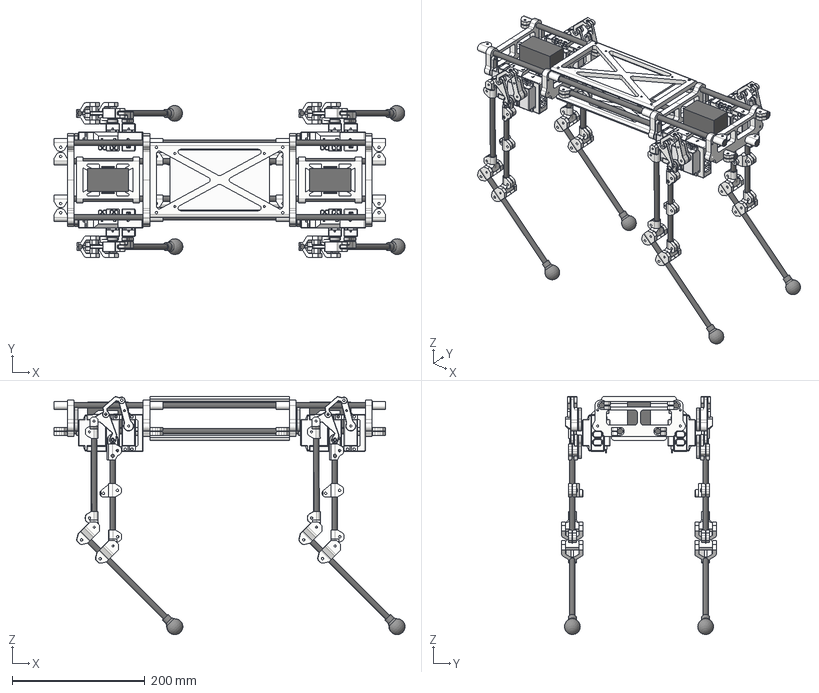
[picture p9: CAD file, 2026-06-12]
cad/step/assembly/Domino_URDF_Parts.step
529.2 x 232.9 x 359.0 mm
clamp_template(Mirror) x 2
L2_clamp(Mirror) x 4
L3_clamp(Mirror) x 4
L2-servo_clamp(Mirror) x 2
pivot(Mirror) x 2
servo_hub_v2(Mirror) x 2
rod_clamp(Mirror) x 2
push_rod(Mirror) x 2
servo3_arm(Mirror) x 2
spring_clamp(Mirror) x 2
foot(Mirror) x 2
servo_arm(Mirror) x 6
L2(Mirror) x 2
rod(Mirror) x 2
L3(Mirror) x 2

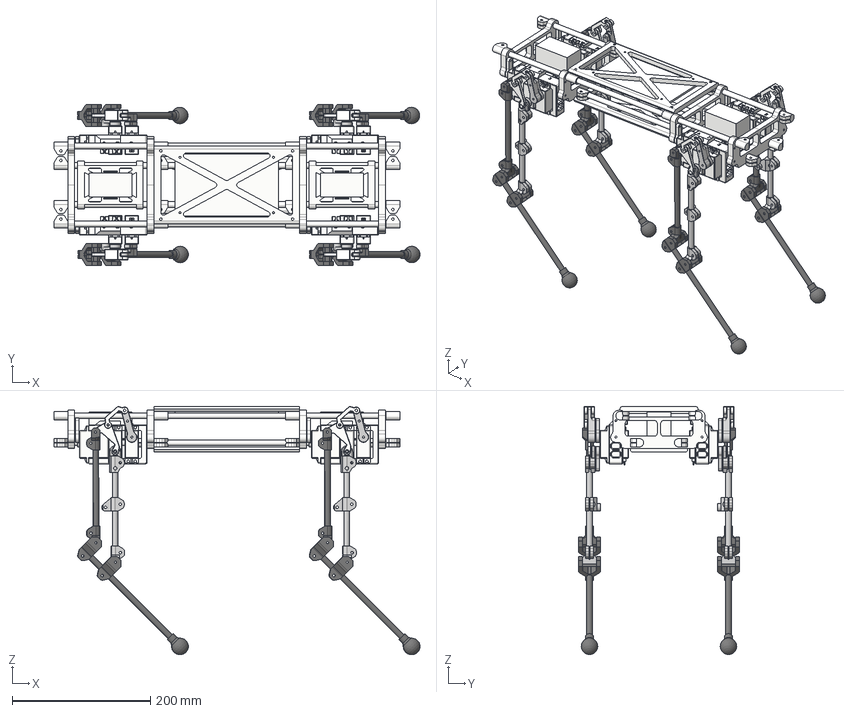
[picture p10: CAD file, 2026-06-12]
cad/step/combined/Domino_URDF_Parts_Combined_Final.step
529.2 x 232.9 x 359.0 mm
pivot (1) (1)
L3 (1) (1)
rod (1) (1)
push_rod (1) (1)
servo_hub_v2 (1) (1)
servo_arm (2) (1) (1)
servo_arm (1) (2) (1) (1)
pivot(Mirror) (1) (1)
servo_arm(Mirror) (2) (1) (1)
push_rod(Mirror) (1) (1)
rod(Mirror) (1) (1)
L3(Mirror) (1) (1)
servo_hub_v2(Mirror) (1) (1)
servo_arm(Mirror) (3) (1) (1)
rod(Mirror) (1)
pivot(Mirror) (1)
push_rod(Mirror) (1)
L3(Mirror) (1)
servo_hub_v2(Mirror) (1)
pivot (1)
rod (1)
L3 (1)
servo_hub_v2 (1)
push_rod (1)
twist_plate_v1 (1)
servo_arm(Mirror) (2) (1) (2)
servo_arm(Mirror) (1) (1) (2)
servo_arm (2) (1) (2)
servo_arm (1) (1) (1) (2)

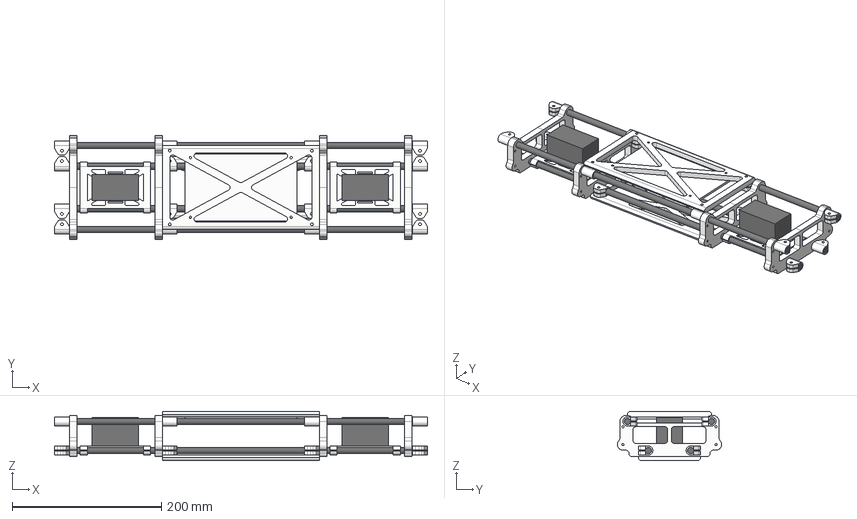
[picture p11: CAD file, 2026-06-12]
cad/step/parts/Body.step
500.0 x 139.7 x 66.2 mm

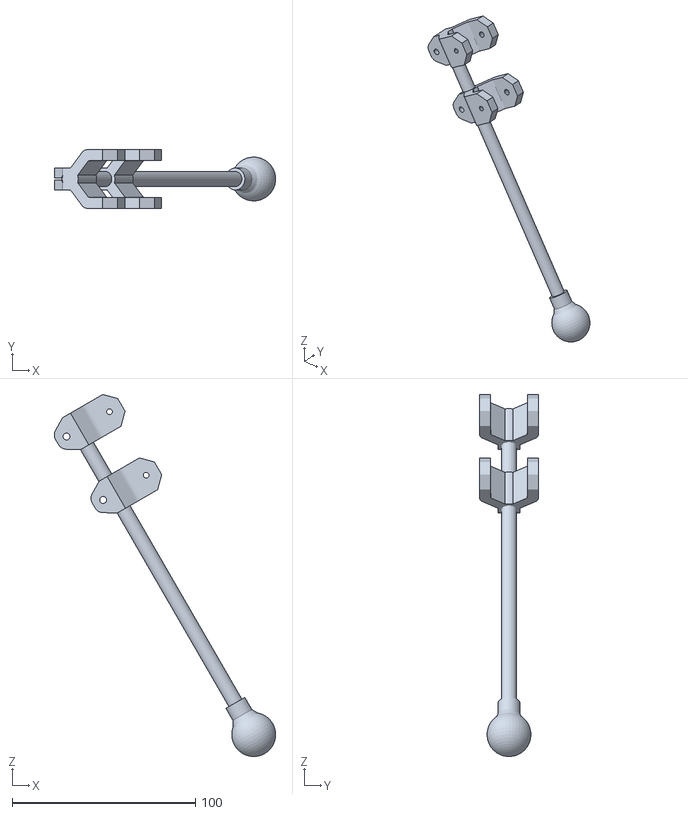
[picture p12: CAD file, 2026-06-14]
simulation/urdf/generated/Domino_URDF_Parts_Combined_Final_description/meshes/DOM_P__22__1.stl
120.9 x 32.0 x 197.6

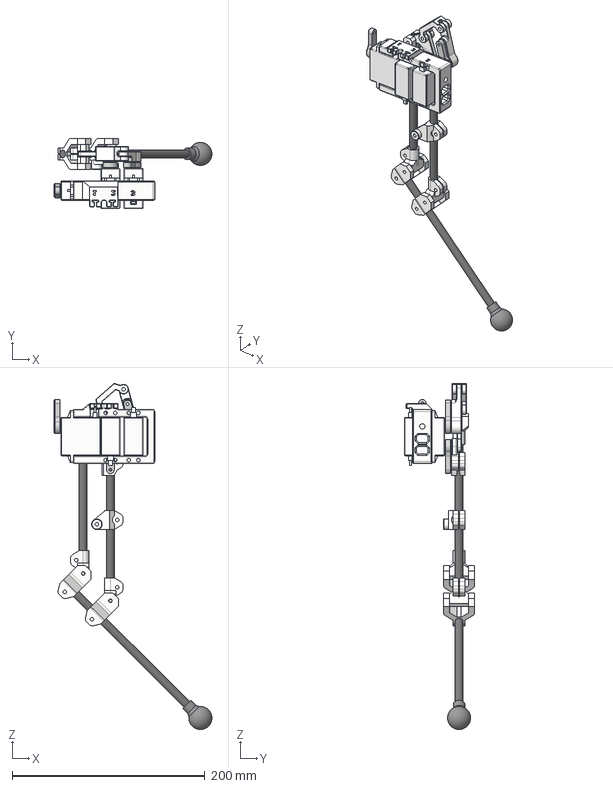
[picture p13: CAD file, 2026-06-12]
cad/step/parts/BL.step
163.9 x 72.6 x 359.0 mm
clamp_template(Mirror)
L2_clamp(Mirror) x 2
L3_clamp(Mirror) x 2
L2-servo_clamp(Mirror)
pivot(Mirror)
servo_hub_v2(Mirror)
rod_clamp(Mirror)
push_rod(Mirror)
servo3_arm(Mirror)
spring_clamp(Mirror)
foot(Mirror)
servo_arm(Mirror) x 3
L2(Mirror)
rod(Mirror)
L3(Mirror)

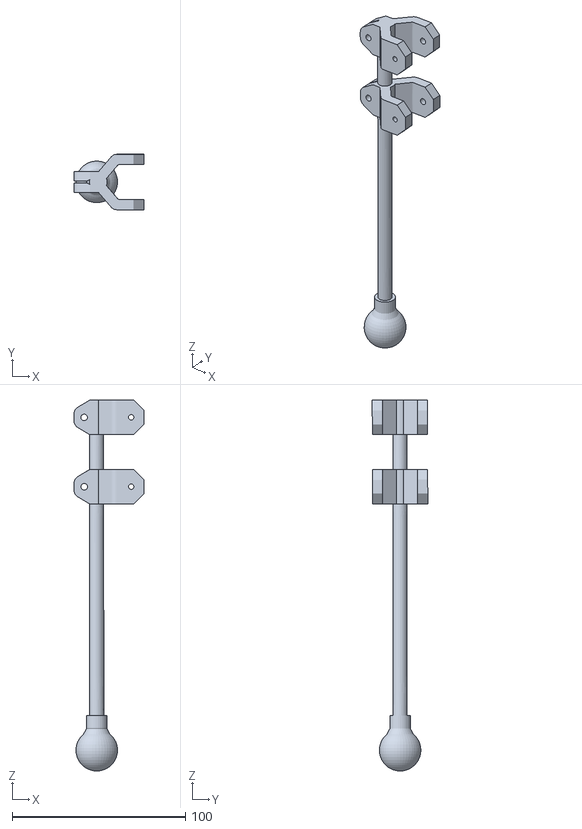
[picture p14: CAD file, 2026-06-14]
simulation/urdf/generated/Domino_URDF_Parts_Combined_Final_description/meshes/DOM_P__1__1.stl
40.6 x 32.0 x 214.0

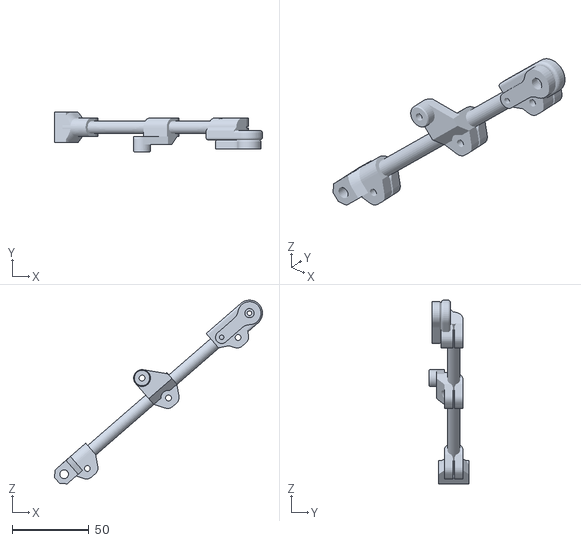
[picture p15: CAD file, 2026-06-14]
simulation/urdf/generated/Domino_URDF_Parts_Combined_Final_description/meshes/DOM_P__16__1.stl
135.4 x 26.1 x 119.6

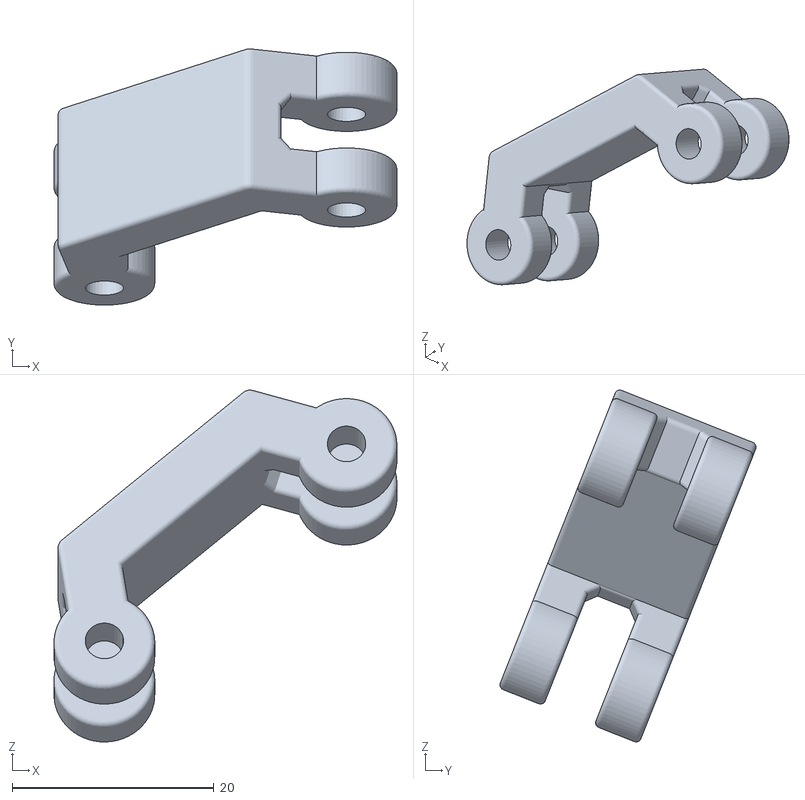
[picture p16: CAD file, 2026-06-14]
simulation/urdf/generated/Domino_URDF_Parts_Combined_Final_description/meshes/DOM_P__9__1.stl
34.0 x 25.4 x 34.9

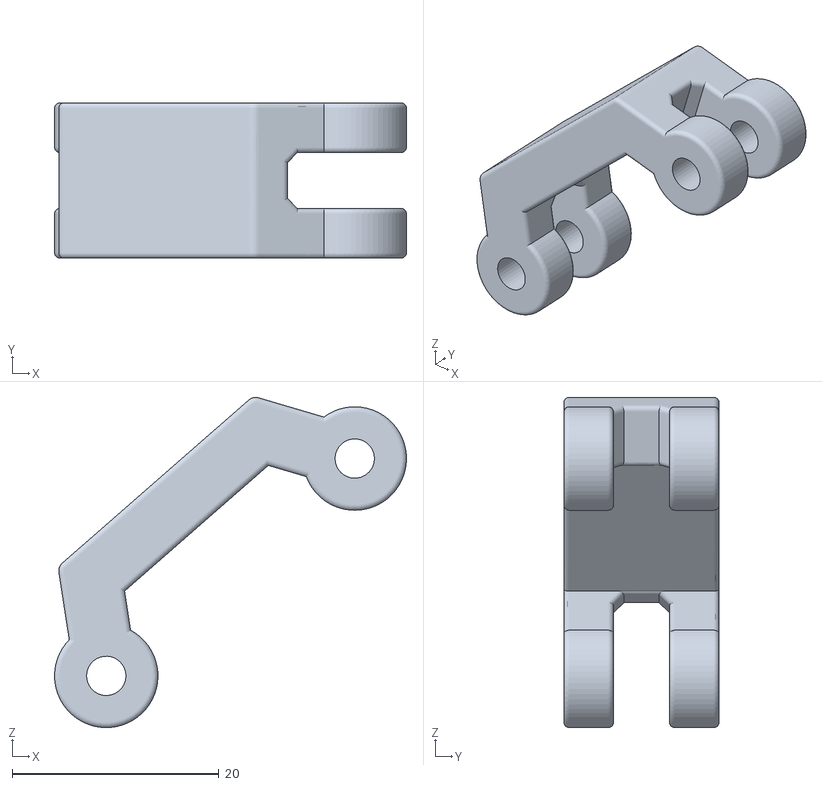
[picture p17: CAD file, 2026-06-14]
simulation/urdf/generated/Domino_URDF_Parts_Combined_Final_description/meshes/DOM_P__20__1.stl
34.0 x 15.0 x 31.9

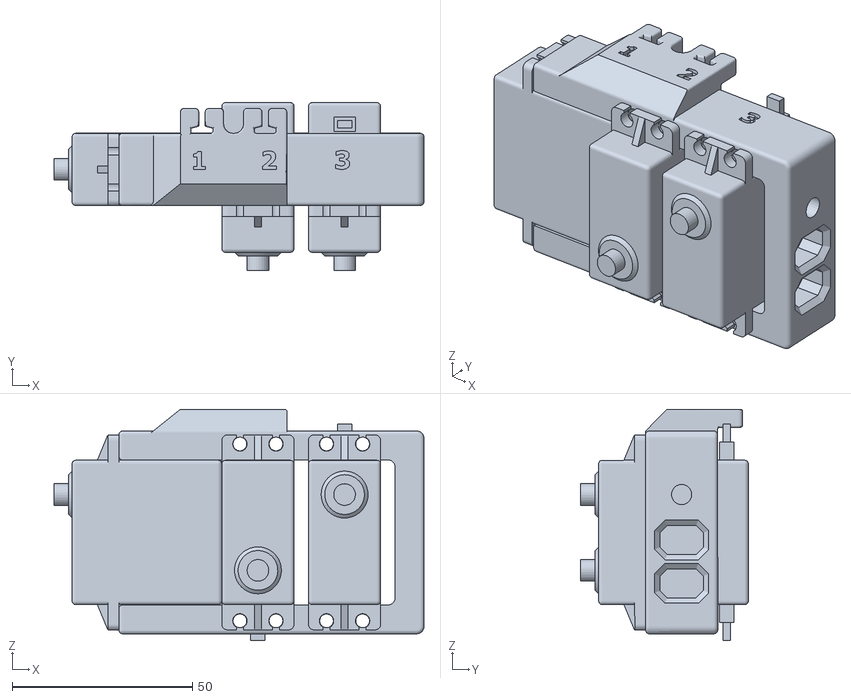
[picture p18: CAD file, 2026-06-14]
simulation/urdf/generated/Domino_URDF_Parts_Combined_Final_description/meshes/DOM_P__4__1.stl
102.5 x 46.5 x 64.1

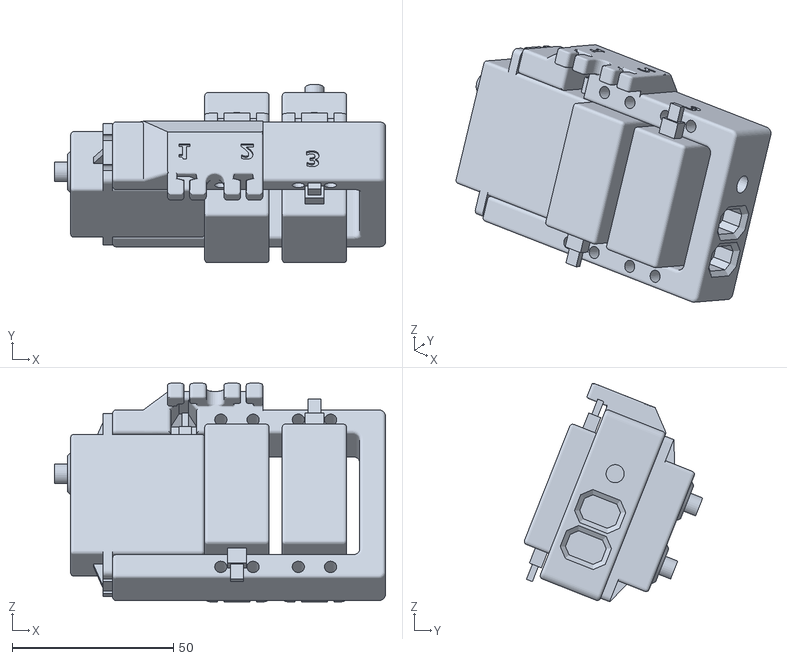
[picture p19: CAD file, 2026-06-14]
simulation/urdf/generated/Domino_URDF_Parts_Combined_Final_description/meshes/DOM_P__12__1.stl
102.5 x 55.3 x 67.7

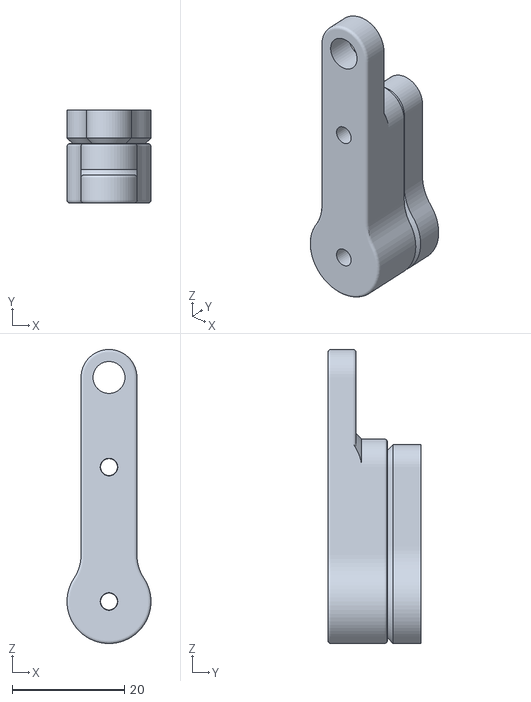
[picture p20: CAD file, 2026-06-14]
simulation/urdf/generated/Domino_URDF_Parts_Combined_Final_description/meshes/DOM_P__19__1.stl
15.0 x 16.6 x 52.5

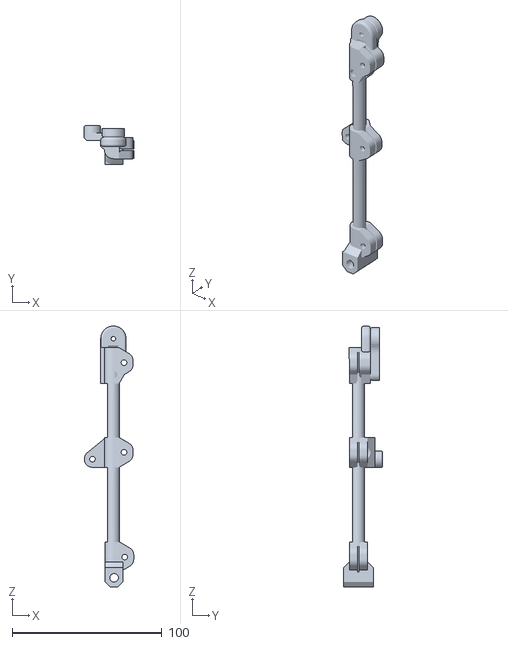
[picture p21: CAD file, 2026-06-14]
simulation/urdf/generated/Domino_URDF_Parts_Combined_Final_description/meshes/DOM_P__5__1.stl
33.1 x 26.1 x 174.5

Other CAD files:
cad/step/combined/Domino_URDF_Parts_Combined.step
cad/step/parts/FR.step
simulation/urdf/generated/Domino_URDF_Parts_Combined_Final_description/meshes/DOM_P__26__1.stl
cad/step/parts/FL.step
cad/step/parts/BR.step
simulation/urdf/generated/Domino_URDF_Parts_Combined_Final_description/meshes/DOM_P_1.stl
simulation/urdf/generated/Domino_URDF_Parts_Combined_Final_description/meshes/DOM_P__10__1.stl
simulation/urdf/generated/Domino_URDF_Parts_Combined_Final_description/meshes/DOM_P__11__1.stl
simulation/urdf/generated/Domino_URDF_Parts_Combined_Final_description/meshes/DOM_P__13__1.stl
simulation/urdf/generated/Domino_URDF_Parts_Combined_Final_description/meshes/DOM_P__14__1.stl
simulation/urdf/generated/Domino_URDF_Parts_Combined_Final_description/meshes/DOM_P__15__1.stl
simulation/urdf/generated/Domino_URDF_Parts_Combined_Final_description/meshes/DOM_P__17__1.stl
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

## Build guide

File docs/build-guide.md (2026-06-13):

# Build And Bring-Up Notes

> Work in progress: this is not a complete assembly manual. It is a cautious bring-up sequence for the firmware and major hardware subsystems. The repo still needs a measured BOM, fastener list, wiring diagram, print settings, rod lengths, and annotated assembly photos before it should be treated as a full public build guide.

## 1. Firmware Environment

Install:

- VS Code.
- PlatformIO IDE extension.
- Git, if cloning the repository.

Build from the repository root:

```powershell
pio run
```

Expected result: PlatformIO builds the `esp32dev` environment without errors.

## 2. ESP32 Upload

Connect the ESP32 by USB and upload:

```powershell
pio run -t upload
```

Open the serial monitor:

```powershell
pio device monitor
```

Expected result: boot/debug logs appear at 115200 baud.

## 3. CRSF / ExpressLRS Receiver Check

Verify the radio link before connecting servos.

Recommended:

- Use the standalone CRSF reader repo first: [ESP32_CRSF_Reader](https://github.com/Blacksheep909/ESP32_CRSF_Reader)
- Confirm decoded channels move in the serial output.
- Confirm switch positions match the expected channel indexes.

Robot firmware expects:

- `Serial2` CRSF input.
- ESP32 RX pin 16.
- ESP32 TX pin 17.
- CRSF baud rate of 420000.

## 4. Servo Power Check

The ESP32 must not power the servos. Use an external regulator or BEC sized for the selected servos.

Check:

- ESP32 ground is connected to servo power ground.
- PCA9685 ground is connected to the same ground.
- Receiver ground is connected to the same ground.
- Servo voltage matches the selected servos.
- The servo rail has no short before battery power is connected.

## 5. One-Servo Test

Before attaching linkages:

1. Power one servo.
2. Command the servo to the expected midpoint.
3. Confirm the horn can be mounted close to mechanical neutral.
4. Confirm the servo does not bind at the intended limits.

Do not use large software trims to hide a badly mounted horn.

## 6. One-Leg Test

The repo does not yet contain a complete mechanical assembly manual, so the first meaningful hardware test should be one leg on the bench.

Check:

- Linkage moves freely.
- Rod ends and pivots do not bind.
- Servo horns clear printed parts.
- The leg can reach neutral without forcing a servo.
- The leg can stow without hitting a hard stop.

## 7. Full Robot On A Stand

Only connect all twelve servos once the receiver, one servo, and one leg have been tested.

First full-system tests:

- Boot with servo power off.
- Confirm CRSF link status.
- Turn servo power on.
- Test stow.
- Test stand.
- Test ride-height presets.
- Test tilt only after stand mode is stable.

## 8. Floor Testing

The robot should only be placed on the floor after:

- All legs move symmetrically on a stand.
- Stand/stow transitions are predictable.
- Link-loss behavior is understood.
- Servo trims are close.
- The power system does not brown out under load.

Start with short tests and keep power easy to disconnect.

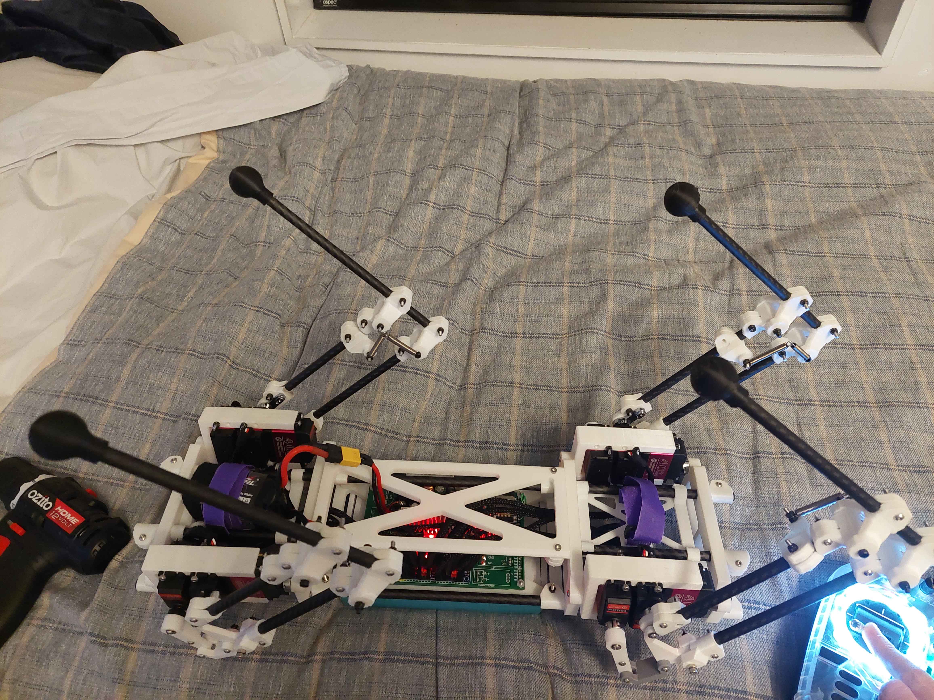
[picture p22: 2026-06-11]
docs/images/robot-dog-v10-build.jpg

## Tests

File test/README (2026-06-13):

Automated firmware tests are not implemented yet.

Good future test targets:

- CRSF frame parsing and CRC rejection.
- 11-bit channel unpacking.
- Link-timeout behavior.
- IK edge cases near the reachable workspace boundary.
- Servo limit clamping.

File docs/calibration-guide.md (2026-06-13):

# Calibration Notes

> Work in progress: these notes document the current calibration approach. They are not a complete calibration tool or validated production procedure.

Calibration is critical on a servo quadruped. Small horn offsets or incorrect trim values can make multiple servos fight the linkage at the same time.

## Servo Centering

The firmware treats 135 degrees as the electrical midpoint for the 270-degree servos.

Before installing horns:

1. Flash the firmware or a simple servo-centering sketch.
2. Command each servo to 135 degrees.
3. Install the horn as close as possible to mechanical neutral.
4. Prefer mechanical re-clocking before large software trims.

## Trim Values

Trim constants live in:

```text
src/leg_controller.h
```

Example:

```cpp
static constexpr float FR_HIP_TRIM_DEG = -45.0f;
```

Trims affect stand, stow, tilt, balance, and future gait work. Tune them in a neutral stand pose with tilt and balance disabled.

## Suggested Trim Order

1. Lift the robot on a stand.
2. Confirm the CRSF link is alive.
3. Enter stand mode.
4. Disable tilt and balance modes.
5. Center all transmitter sticks.
6. Adjust hip trims so the legs point symmetrically.
7. Adjust upper/lower trims so the body sits level.
8. Test stow.
9. Test stand again.
10. Repeat until transitions are smooth.

## Healthy Behavior

- Body is roughly level in stand.
- Front legs mirror each other.
- Rear legs mirror each other.
- Feet land in predictable positions.
- Stow transition does not kick the legs sideways.
- Tilt returns to neutral cleanly when released.

## Warning Signs

- A servo buzzes loudly at neutral.
- A linkage contacts a hard stop.
- One side needs much larger trims than the other.
- The body twists when entering stand.
- A foot moves sideways during stow.

If trims become extreme, stop and inspect horn clocking, servo orientation, channel mapping, and mechanical assembly before continuing.

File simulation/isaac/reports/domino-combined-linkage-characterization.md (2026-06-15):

# Domino Combined Linkage Characterization

This report records the first motion-characterization pass for the simplified CAD-derived DOM_P__4__1 leg mechanism.

## Result

Status: **passed for finite-state PhysX runtime, not yet calibrated for policy use**.

The combined linkage mode uses:

- Lower driven input: `Revolute 59`
- Upper driven input: `Revolute 58`
- Shared coupler: `DOM_P_1`
- Lower closure: `Revolute 25` / `Revolute 26`
- Upper closure: direct `Revolute 32` / `Revolute 51` pin closure

## Runtime Command Shape

```powershell
<isaac-python> simulation/isaac/prototypes/pin_linkage/run_pin_linkage.py `
  --headless `
  --geometry domino-combined-leg `
  --steps 1000 `
  --fit-start-step 60 `
  --drive-amplitude-deg 2 `
  --secondary-drive-amplitude-deg 2 `
  --drive-frequency-hz 0.2 `
  --secondary-drive-frequency-hz 0.2 `
  --report-path <output-folder>/domino_combined_leg_characterization.json `
  --save-usd <output-folder>/domino_combined_leg_characterization.usd
```

## Closure Stability

| Metric | Result |
| --- | ---: |
| Physics steps | `1000` |
| Physics dt | `0.005 s` |
| Max lower closure error | `0.00001490 m` |
| Max upper closure error | `0.00000294 m` |
| Max body linear speed | `0.037481 m/s` |

The combined leg did not produce non-finite poses or velocities. Both loop closures stayed bounded under simultaneous two-drive motion.

## Motion Characterization

| Quantity | Min | Max | Final |
| --- | ---: | ---: | ---: |
| Lower drive target, deg | `-17.000000` | `-13.000000` | `-15.012566` |
| Upper drive target, deg | `-2.000000` | `2.000000` | `1.999961` |
| Lower driver body pitch, deg | `-1.820513` | `-0.491281` | `-1.381006` |
| Upper driver body pitch, deg | `-1.628365` | `-0.182148` | `-1.106722` |
| Coupler body pitch, deg | `-1.158683` | `-0.208075` | `-0.826778` |
| Lower diagonal relative to coupler, deg | `-0.635458` | `-0.278530` | `-0.531013` |
| Upper driver relative to coupler, deg | `-0.472943` | `0.025928` | `-0.279944` |

Drive tracking error against simple world/body-pitch measurements:

| Drive | Min error | Max error | Final error |
| --- | ---: | ---: | ---: |
| `lower_drive_revolute_59` | `11.662777 deg` | `15.243038 deg` | `13.631561 deg` |
| `upper_drive_revolute_58` | `-3.115988 deg` | `0.447099 deg` | `-3.106682 deg` |

These tracking-error numbers use simple body-pitch measurements as a proxy for the effective linkage angle. They are useful for first-pass characterization, but they are not the final PhysX joint-state mapping that should feed a policy.

## Local Linear Calibration Fit

The latest characterization run fits a local linear model after the first 60 startup steps:

```text
output_deg = intercept + lower_coeff * lower_drive_target_deg + upper_coeff * upper_drive_target_deg
```

Fit inputs:

- Sample count: `940`
- Matrix rank: `3`
- Lower input: `lower_drive_revolute_59`
- Upper input: `upper_drive_revolute_58`

| Output proxy | Intercept | Lower coeff | Upper coeff | RMSE | R^2 |
| --- | ---: | ---: | ---: | ---: | ---: |
| Lower driver to ground, deg | `0.081800` | `0.108579` | `0.083813` | `0.000784` | `0.999983` |
| Upper driver to ground, deg | `0.080162` | `0.094291` | `0.114446` | `0.000931` | `0.999979` |
| Coupler to ground, deg | `0.056903` | `0.068106` | `0.069478` | `0.000582` | `0.999982` |
| Lower diagonal to coupler, deg | `0.022524` | `0.038466` | `0.012053` | `0.000217` | `0.999986` |
| Upper driver to coupler, deg | `0.023260` | `0.026185` | `0.044969` | `0.000362` | `0.999974` |

This is a small-range calibration around the conservative `-15 deg` lower-drive centre and `0 deg` upper-drive centre. It proves the simulated pin-joint linkage has a stable, repeatable relationship between commanded inputs and measured output proxies over this range. It does not yet prove that the same coefficients are valid across the full servo range or under ground contact.

## Interpretation

The direct closure representation fixed the previous upper-loop drift. The remaining issue is not loop explosion; it is turning this local fit into a useful training-coordinate mapping.

The lower drive target range is much larger than the measured lower driver body-pitch range. That means the simplified PhysX drive target is not a direct substitute for the `lower_linkage` coordinate used by `prototypes/one_leg`. Before this becomes a training asset, the fitted mapping needs to be compared against the clean one-leg abstraction and then converted into actuator targets, joint limits, and reset-safe default poses.

## Next Work

1. Run one-input sweeps for the lower and upper drives separately so the cross-coupling terms can be checked independently.
2. Compare the fitted output proxies to `upper_pitch` and `lower_linkage` in `prototypes/one_leg`.
3. Replace the proxy body-pitch measurement with a cleaner output coordinate before feeding it to an RL environment.
4. Only after the mapping is stable, merge the constrained linkage into the one-leg USD/asset path.

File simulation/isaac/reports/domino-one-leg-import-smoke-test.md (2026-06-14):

# Domino One-Leg Import Smoke Test

This report records the first Isaac Lab import test for the simplified one-leg prototype under `simulation/isaac/prototypes/one_leg`.

## Result

Status: **passed for clean one-leg USD generation**.

The prototype URDF imported successfully through Isaac Lab's `convert_urdf.py` workflow and wrote the expected root USD plus generated configuration layers.

Unlike the raw CAD-generated full robot URDF, this prototype did not trigger joint-name sanitation warnings. The three driven joints already use readable names:

- `hip_ab_ad`
- `upper_pitch`
- `lower_linkage`

## What This Confirms

- The simplified one-leg model is valid enough for Isaac's URDF importer.
- The model has a clean tree structure with one fixed foot joint and three driven revolute joints.
- The prototype is a better starting point for control bring-up than the direct CAD URDF export.

## What This Does Not Confirm Yet

- Joint axes have not yet been visually confirmed against the physical Domino leg.
- Contact behavior and collision quality have not been tested.
- The actuator gains in `domino_one_leg_cfg.py` are first-pass placeholders.
- The passive four-bar linkage is not physically constrained yet.

## Next Test

The next runtime test should spawn the generated USD in Isaac Lab, reset the articulation, and sweep each driven joint one at a time through conservative limits.

That test should answer three practical questions:

1. Does each joint rotate around the expected axis?
2. Do positive and negative commands match the firmware convention?
3. Does the simplified collision model remain stable under gravity and reset?

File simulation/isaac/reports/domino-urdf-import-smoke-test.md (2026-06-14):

# Domino URDF Import Smoke Test

This report records the first Isaac Sim / Isaac Lab smoke test for the generated Domino URDF export.

## Result

Status: **passed for raw USD generation, not passed as a training-ready robot model**.

The generated URDF was imported through Isaac Lab's `convert_urdf.py` tool in a local Isaac Sim 5.1 / Isaac Lab environment. The command completed and wrote a USD stage plus the related generated configuration layers.

The import is useful because it proves that the current URDF package and meshes can be consumed by the Isaac tooling. It does not mean the resulting asset is ready for reinforcement learning or accurate physics.

## Important Warnings

- Joint names with spaces were sanitized by the importer, for example `Revolute 1` became `Revolute_1`.
- The source URDF still contains duplicate link names and loop-style child reuse, as documented in [`domino-urdf-topology.md`](domino-urdf-topology.md).
- The four-bar / closed-chain leg linkage still needs a deliberate simulation model rather than a blind CAD-mate import.
- The generated smoke-test USD should be treated as a local build artifact until asset references, scale, physics settings, and joint naming have been reviewed.

## Reproduction

Use the helper script from the repository root:

```powershell
powershell -ExecutionPolicy Bypass -File simulation/isaac/run-domino-urdf-import.ps1 `
  -IsaacLabRoot <path-to-IsaacLab> `
  -IsaacPython <path-to-isaac-python> `
  -OutputUsd <output-folder>/domino_raw_import.usd `
  -AcceptEula
```

The script keeps local install paths outside the repo. It also sets conservative import options for early bring-up:

- `--merge-joints`
- `--joint-stiffness 0.0`
- `--joint-damping 0.0`
- `--joint-target-type none`
- `--headless`

These settings produce a neutral imported asset so drives and actuator models can be configured intentionally in Isaac Lab later.

## Next Work

1. Build a clean one-leg USD articulation with readable joint names and simplified collision.
2. Validate joint axes, limits, scale, and reset behavior in Isaac.
3. Add passive linkage geometry as visual-only first.
4. Add loop-closing constraints only after the simplified driven model is stable.
5. Duplicate the validated leg into the full quadruped and expose the twelve real driven joints to Isaac Lab.

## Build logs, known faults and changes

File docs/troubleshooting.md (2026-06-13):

# Troubleshooting Notes

> Work in progress: this page covers common bring-up checks. It is not a complete fault tree for every hardware configuration.

## PlatformIO Does Not Build

Check:

- PlatformIO extension is installed.
- The repository root is open, not only the `src` folder.
- `platformio.ini` is visible in the VS Code Explorer.
- The active environment is `esp32dev`.

Command:

```powershell
pio run
```

## Upload Fails

Check:

- USB cable supports data.
- Correct COM port is selected.
- ESP32 is not held in reset.
- No other serial monitor is using the port.

Try unplugging and reconnecting the ESP32 before uploading again.

## No Serial Output

Check:

- Monitor speed is 115200.
- ESP32 is running the uploaded firmware.
- USB cable supports data.

Command:

```powershell
pio device monitor
```

## CRSF Link Not Alive

Check:

- Receiver TX is wired to ESP32 RX2 / GPIO 16.
- Receiver and ESP32 share ground.
- Receiver is powered.
- Radio is bound to the receiver.
- Receiver is configured for CRSF output.
- Firmware baud rate is 420000.

Use [ESP32_CRSF_Reader](https://github.com/Blacksheep909/ESP32_CRSF_Reader) to debug the receiver without servo code.

## Servos Do Not Move

Check:

- External servo power is on.
- Servo power ground is common with ESP32 ground.
- PCA9685 is powered.
- PCA9685 I2C wiring is correct.
- Servo plug orientation is correct.
- The robot is receiving a valid stand command.

## Servos Twitch Or Brown Out

Likely causes:

- Regulator cannot supply enough current.
- Wiring is too thin or too long.
- Grounding is poor.
- Battery voltage is sagging.
- Servos are fighting mechanical stops.

Test with one servo or one leg before powering all twelve.

## One Leg Moves Backwards

Check:

- Servo channel assignment.
- Servo horn orientation.
- `hipDir`, `upperDir`, and `lowerDir` in the leg configuration.
- Left/right mechanical mirroring.

Do not compensate for wiring or channel mistakes with random trim values.

## Tilt Or Balance Mode Behaves Incorrectly

Check:

- Robot is stable in stand mode first.
- IMU is detected.
- IMU mounting orientation matches the assumptions in `src/main.cpp`.
- RC switch channels match the transmitter setup.
- Sticks are centered when testing neutral pose.

Balance mode is experimental and should be treated as a tuning area, not a finished stabilizer.

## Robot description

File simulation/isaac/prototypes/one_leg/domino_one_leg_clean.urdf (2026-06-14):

<?xml version="1.0"?>
<robot name="domino_one_leg_clean">
  <material name="domino_carbon">
    <color rgba="0.08 0.09 0.10 1.0"/>
  </material>
  <material name="domino_printed">
    <color rgba="0.65 0.68 0.70 1.0"/>
  </material>
  <material name="domino_joint">
    <color rgba="0.15 0.28 0.42 1.0"/>
  </material>
  <material name="domino_foot">
    <color rgba="0.02 0.02 0.02 1.0"/>
  </material>

  <link name="body_mount">
    <inertial>
      <origin xyz="0 0 0" rpy="0 0 0"/>
      <mass value="0.20"/>
      <inertia ixx="0.0010" ixy="0" ixz="0" iyy="0.0010" iyz="0" izz="0.0010"/>
    </inertial>
    <visual>
      <origin xyz="0 0 0" rpy="0 0 0"/>
      <geometry>
        <box size="0.090 0.070 0.035"/>
      </geometry>
      <material name="domino_carbon"/>
    </visual>
    <collision>
      <origin xyz="0 0 0" rpy="0 0 0"/>
      <geometry>
        <box size="0.090 0.070 0.035"/>
      </geometry>
    </collision>
  </link>

  <link name="hip_carriage">
    <inertial>
      <origin xyz="0 0 -0.010" rpy="0 0 0"/>
      <mass value="0.10"/>
      <inertia ixx="0.0004" ixy="0" ixz="0" iyy="0.0004" iyz="0" izz="0.0004"/>
    </inertial>
    <visual>
      <origin xyz="0 0 -0.010" rpy="0 0 0"/>
      <geometry>
        <box size="0.060 0.055 0.030"/>
      </geometry>
      <material name="domino_joint"/>
    </visual>
    <collision>
      <origin xyz="0 0 -0.010" rpy="0 0 0"/>
      <geometry>
        <box size="0.060 0.055 0.030"/>
      </geometry>
    </collision>
  </link>

  <joint name="hip_ab_ad" type="revolute">
    <origin xyz="0 0 0" rpy="0 0 0"/>
    <parent link="body_mount"/>
    <child link="hip_carriage"/>
    <axis xyz="1 0 0"/>
    <limit lower="-0.523599" upper="0.523599" effort="8.0" velocity="6.0"/>
    <dynamics damping="0.05" friction="0.0"/>
  </joint>

  <link name="upper_link">
    <inertial>
      <origin xyz="0 0 -0.080" rpy="0 0 0"/>
      <mass value="0.12"/>
      <inertia ixx="0.0005" ixy="0" ixz="0" iyy="0.0005" iyz="0" izz="0.00008"/>
    </inertial>
    <visual>
      <origin xyz="0 0 -0.080" rpy="0 0 0"/>
      <geometry>
        <cylinder radius="0.012" length="0.160"/>
      </geometry>
      <material name="domino_printed"/>
    </visual>
    <visual>
      <origin xyz="0.018 0 -0.080" rpy="0 0 0"/>
      <geometry>
        <cylinder radius="0.004" length="0.145"/>
      </geometry>
      <material name="domino_carbon"/>
    </visual>
    <visual>
      <origin xyz="-0.018 0 -0.080" rpy="0 0 0"/>
      <geometry>
        <cylinder radius="0.004" length="0.145"/>
      </geometry>
      <material name="domino_carbon"/>
    </visual>
    <collision>
      <origin xyz="0 0 -0.080" rpy="0 0 0"/>
      <geometry>
        <cylinder radius="0.014" length="0.160"/>
      </geometry>
    </collision>
  </link>

  <joint name="upper_pitch" type="revolute">
    <origin xyz="0 0.038 -0.021" rpy="0 0 0"/>
    <parent link="hip_carriage"/>
    <child link="upper_link"/>
    <axis xyz="0 1 0"/>
    <limit lower="-0.523599" upper="1.047198" effort="8.0" velocity="6.0"/>
    <dynamics damping="0.05" friction="0.0"/>
  </joint>

  <link name="lower_link">
    <inertial>
      <origin xyz="0 0 -0.0765" rpy="0 0 0"/>
      <mass value="0.10"/>
      <inertia ixx="0.0004" ixy="0" ixz="0" iyy="0.0004" iyz="0" izz="0.00006"/>
    </inertial>
    <visual>
      <origin xyz="0 0 -0.0765" rpy="0 0 0"/>
      <geometry>
        <cylinder radius="0.010" length="0.153"/>
      </geometry>
      <material name="domino_printed"/>
    </visual>
    <visual>
      <origin xyz="0.016 0 -0.0765" rpy="0 0 0"/>
      <geometry>
        <cylinder radius="0.0035" length="0.135"/>
      </geometry>
      <material name="domino_carbon"/>
    </visual>
    <visual>
      <origin xyz="-0.016 0 -0.0765" rpy="0 0 0"/>
      <geometry>
        <cylinder radius="0.0035" length="0.135"/>
      </geometry>
      <material name="domino_carbon"/>
    </visual>
    <collision>
      <origin xyz="0 0 -0.0765" rpy="0 0 0"/>
      <geometry>
        <cylinder radius="0.012" length="0.153"/>
      </geometry>
    </collision>
  </link>

  <joint name="lower_linkage" type="revolute">
    <origin xyz="0 0 -0.160" rpy="0 0 0"/>
    <parent link="upper_link"/>
    <child link="lower_link"/>
    <axis xyz="0 1 0"/>
    <limit lower="-2.094395" upper="0.0" effort="8.0" velocity="6.0"/>
    <dynamics damping="0.05" friction="0.0"/>
  </joint>

  <link name="foot">
    <inertial>
      <origin xyz="0 0 0" rpy="0 0 0"/>
      <mass value="0.02"/>
      <inertia ixx="0.00003" ixy="0" ixz="0" iyy="0.00003" iyz="0" izz="0.00003"/>
    </inertial>
    <visual>
      <origin xyz="0 0 0" rpy="0 0 0"/>
      <geometry>
        <sphere radius="0.022"/>
      </geometry>
      <material name="domino_foot"/>
    </visual>
    <collision>
      <origin xyz="0 0 0" rpy="0 0 0"/>
      <geometry>
        <sphere radius="0.022"/>
      </geometry>
    </collision>
  </link>

  <joint name="foot_fixed" type="fixed">
    <origin xyz="0 0 -0.153" rpy="0 0 0"/>
    <parent link="lower_link"/>
    <child link="foot"/>
  </joint>
</robot>

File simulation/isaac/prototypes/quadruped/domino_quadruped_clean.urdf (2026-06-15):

<?xml version="1.0" ?>
<robot name="domino_quadruped_clean">
  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
  <link name="base_link">
    <inertial>
      <origin xyz="0.000000 0.000000 0.000000" rpy="0 0 0"/>
      <mass value="1.200000"/>
      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
    </inertial>
    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
  </link>
  <link name="dom_p_4_1_hip_carriage">
    <inertial>
      <origin xyz="0.000000 0.000000 -0.010000" rpy="0 0 0"/>
      <mass value="0.100000"/>
      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
    </inertial>
    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
  </link>
  <link name="dom_p_4_1_upper_link">
    <inertial>
      <origin xyz="0.000000 0.000000 -0.080000" rpy="0 0 0"/>
      <mass value="0.120000"/>
      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
    </inertial>
    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
  </link>
  <link name="dom_p_4_1_lower_link">
    <inertial>
      <origin xyz="0.000000 0.000000 -0.076500" rpy="0 0 0"/>
      <mass value="0.100000"/>
      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
    </inertial>
    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
  </link>
  <link name="dom_p_4_1_foot">
    <inertial>
      <origin xyz="0.000000 0.000000 0.000000" rpy="0 0 0"/>
      <mass value="0.030000"/>
      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
    </inertial>
    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
  </link>
  <joint name="dom_p_4_1_shoulder_ab_ad" type="revolute">
    <origin xyz="0.167500 -0.062375 0.000000" rpy="0 0 0"/>
    <parent link="base_link"/>
    <child link="dom_p_4_1_hip_carriage"/>
    <axis xyz="-1.000000 0.000000 0.000000"/>
    <limit lower="-0.523599" upper="0.523599" effort="8.0" velocity="6.0"/>
    <dynamics damping="0.05" friction="0.0"/>
  </joint>
  <joint name="dom_p_4_1_upper_pitch" type="revolute">
    <origin xyz="0.080500 -0.028000 0.000000" rpy="0 0 0"/>
    <parent link="dom_p_4_1_hip_carriage"/>
    <child link="dom_p_4_1_upper_link"/>
    <axis xyz="0.000000 1.000000 0.000000"/>
    <limit lower="-0.523599" upper="1.047198" effort="8.0" velocity="6.0"/>
    <dynamics damping="0.05" friction="0.0"/>
  </joint>
  <joint name="dom_p_4_1_lower_linkage" type="revolute">
    <origin xyz="0.000000 0.000000 -0.160000" rpy="0 0 0"/>
    <parent link="dom_p_4_1_upper_link"/>
    <child link="dom_p_4_1_lower_link"/>
    <axis xyz="0.000000 1.000000 0.000000"/>
    <limit lower="-2.094395" upper="0.000000" effort="8.0" velocity="6.0"/>
    <dynamics damping="0.05" friction="0.0"/>
  </joint>
  <joint name="dom_p_4_1_foot_fixed" type="fixed">
    <origin xyz="0.000000 0.000000 -0.153000" rpy="0 0 0"/>
    <parent link="dom_p_4_1_lower_link"/>
    <child link="dom_p_4_1_foot"/>
  </joint>
  <link name="dom_p_12_1_hip_carriage">
    <inertial>
      <origin xyz="0.000000 0.000000 -0.010000" rpy="0 0 0"/>
      <mass value="0.100000"/>
      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
    </inertial>
    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
  </link>
  <link name="dom_p_12_1_upper_link">
    <inertial>
      <origin xyz="0.000000 0.000000 -0.080000" rpy="0 0 0"/>
      <mass value="0.120000"/>
      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
    </inertial>
    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
  </link>
  <link name="dom_p_12_1_lower_link">
    <inertial>
      <origin xyz="0.000000 0.000000 -0.076500" rpy="0 0 0"/>
      <mass value="0.100000"/>
      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
    </inertial>
    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
  </link>
  <link name="dom_p_12_1_foot">
    <inertial>
      <origin xyz="0.000000 0.000000 0.000000" rpy="0 0 0"/>
      <mass value="0.030000"/>
      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
    </inertial>
    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
  </link>
  <joint name="dom_p_12_1_shoulder_ab_ad" type="revolute">
    <origin xyz="0.167500 0.062375 0.000000" rpy="0 0 0"/>
    <parent link="base_link"/>
    <child link="dom_p_12_1_hip_carriage"/>
    <axis xyz="1.000000 0.000000 0.000000"/>
    <limit lower="-0.523599" upper="0.523599" effort="8.0" velocity="6.0"/>
    <dynamics damping="0.05" friction="0.0"/>
  </joint>
  <joint name="dom_p_12_1_upper_pitch" type="revolute">
    <origin xyz="0.080500 0.028000 0.000000" rpy="0 0 0"/>
    <parent link="dom_p_12_1_hip_carriage"/>
    <child link="dom_p_12_1_upper_link"/>
    <axis xyz="0.000000 1.000000 0.000000"/>
    <limit lower="-0.523599" upper="1.047198" effort="8.0" velocity="6.0"/>
    <dynamics damping="0.05" friction="0.0"/>
  </joint>
  <joint name="dom_p_12_1_lower_linkage" type="revolute">
    <origin xyz="0.000000 0.000000 -0.160000" rpy="0 0 0"/>
    <parent link="dom_p_12_1_upper_link"/>
    <child link="dom_p_12_1_lower_link"/>
    <axis xyz="0.000000 1.000000 0.000000"/>
    <limit lower="-2.094395" upper="0.000000" effort="8.0" velocity="6.0"/>
    <dynamics damping="0.05" friction="0.0"/>
  </joint>
  <joint name="dom_p_12_1_foot_fixed" type="fixed">
    <origin xyz="0.000000 0.000000 -0.153000" rpy="0 0 0"/>
    <parent link="dom_p_12_1_lower_link"/>
    <child link="dom_p_12_1_foot"/>
  </joint>
  <link name="dom_p_25_1_hip_carriage">
    <inertial>
      <origin xyz="0.000000 0.000000 -0.010000" rpy="0 0 0"/>
      <mass value="0.100000"/>
      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
    </inertial>
    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
  </link>
  <link name="dom_p_25_1_upper_link">
    <inertial>
      <origin xyz="0.000000 0.000000 -0.080000" rpy="0 0 0"/>
      <mass value="0.120000"/>
      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
    </inertial>
    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
  </link>
  <link name="dom_p_25_1_lower_link">
    <inertial>
      <origin xyz="0.000000 0.000000 -0.076500" rpy="0 0 0"/>
      <mass value="0.100000"/>
      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
    </inertial>
    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
  </link>
  <link name="dom_p_25_1_foot">
    <inertial>
      <origin xyz="0.000000 0.000000 0.000000" rpy="0 0 0"/>
      <mass value="0.030000"/>
      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
    </inertial>
    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
  </link>
  <joint name="dom_p_25_1_shoulder_ab_ad" type="revolute">
    <origin xyz="-0.167500 0.062375 0.000000" rpy="0 0 0"/>
    <parent link="base_link"/>
    <child link="dom_p_25_1_hip_carriage"/>
    <axis xyz="1.000000 0.000000 0.000000"/>
    <limit lower="-0.523599" upper="0.523599" effort="8.0" velocity="6.0"/>
    <dynamics damping="0.05" friction="0.0"/>
  </joint>
  <joint name="dom_p_25_1_upper_pitch" type="revolute">
    <origin xyz="0.080500 0.028000 0.000000" rpy="0 0 0"/>
    <parent link="dom_p_25_1_hip_carriage"/>
    <child link="dom_p_25_1_upper_link"/>
    <axis xyz="0.000000 1.000000 0.000000"/>
    <limit lower="-0.523599" upper="1.047198" effort="8.0" velocity="6.0"/>
    <dynamics damping="0.05" friction="0.0"/>
  </joint>
  <joint name="dom_p_25_1_lower_linkage" type="revolute">
    <origin xyz="0.000000 0.000000 -0.160000" rpy="0 0 0"/>
    <parent link="dom_p_25_1_upper_link"/>
    <child link="dom_p_25_1_lower_link"/>
    <axis xyz="0.000000 1.000000 0.000000"/>
    <limit lower="-2.094395" upper="0.000000" effort="8.0" velocity="6.0"/>
    <dynamics damping="0.05" friction="0.0"/>
  </joint>
  <joint name="dom_p_25_1_foot_fixed" type="fixed">
    <origin xyz="0.000000 0.000000 -0.153000" rpy="0 0 0"/>
    <parent link="dom_p_25_1_lower_link"/>
    <child link="dom_p_25_1_foot"/>
  </joint>
  <link name="dom_p_21_1_hip_carriage">
    <inertial>
      <origin xyz="0.000000 0.000000 -0.010000" rpy="0 0 0"/>
      <mass value="0.100000"/>
      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
    </inertial>
    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
  </link>
  <link name="dom_p_21_1_upper_link">
    <inertial>
      <origin xyz="0.000000 0.000000 -0.080000" rpy="0 0 0"/>
      <mass value="0.120000"/>
      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
    </inertial>
    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
  </link>
  <link name="dom_p_21_1_lower_link">
    <inertial>
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

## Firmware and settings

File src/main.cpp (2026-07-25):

// High‑level control for a 3‑DoF quadruped with CRSF input and a simple
// "body tilt" mode. This file is intentionally verbose with comments to
// capture the mechanical / kinematic assumptions for future maintainers.
//
// Coordinate frames
// -----------------
// World/body frame:
//   - Origin: center of the hip rectangle in X/Y.
//   - +X = forward (toward the head).
//   - +Y = left (dog's left when viewed from behind).
//   - +Z = up.
//
// Leg frame (what IK() expects):
//   - Origin at the hip rotation center.
//   - +X forward, +Y left, +Z downward from the hip toward the ground.
//
// Body plate geometry
// -------------------
// The body is approximated as a rigid plate with 4 hip locations defined
// from CAD. The constants below encode half‑length/width of that plate and
// the nominal stand foot locations.
//
// Hip positions in body frame (x, y, z):
//   - FL: (+BODY_HALF_LENGTH_X, +BODY_HALF_WIDTH_Y, HIP_HEIGHT_Z)
//   - FR: (+BODY_HALF_LENGTH_X, -BODY_HALF_WIDTH_Y, HIP_HEIGHT_Z)
//   - BL: (-BODY_HALF_LENGTH_X, +BODY_HALF_WIDTH_Y, HIP_HEIGHT_Z)
//   - BR: (-BODY_HALF_LENGTH_X, -BODY_HALF_WIDTH_Y, HIP_HEIGHT_Z)
//
// Feet are placed roughly FOOT_OUT_OFFSET_Y laterally and FOOT_BACK_OFFSET_X
// behind the hip in X, with STAND_HEIGHT_Z as the nominal ground height.
//
// Important hardware detail: all hip servos are oriented the same way in
// world space. This is reflected in leg_controller.cpp where hipDir = +1
// for every leg; left legs mirror only the upper/lower joints.

#include <Arduino.h>
#include <Wire.h>
#include <Adafruit_PWMServoDriver.h>
#include <Ramp.h>
#include <math.h>

#include "crsf.h"
#include "leg_controller.h"
#include "imu.h"

enum LegIndex { LEG_FL = 0, LEG_FR = 1, LEG_BL = 2, LEG_BR = 3 };
constexpr int kLegCount = 4;

enum StandState { STOW = 0, SIT = 1, STAND = 2 };
StandState standState = STOW;
bool tiltModeActive = false;
extern float currentTargetZ;
float lastPoseZ = 0.0f;

constexpr float BODY_HALF_LENGTH_X = 167.0f;  // half distance front <-> back hips
constexpr float BODY_HALF_WIDTH_Y = 62.0f;    // half distance left <-> right hips
constexpr float HIP_HEIGHT_Z = 0.0f;          // body plate Z relative to world origin
constexpr float FOOT_BACK_OFFSET_X = -15.75f; // foot is slightly behind the hip in X
constexpr float FOOT_OUT_OFFSET_Y = 100.0f;   // lateral distance from body center line
constexpr float STAND_HEIGHT_Z = -280.0f;     // nominal foot Z in world frame (down)
constexpr float kStandPoseToleranceMm = 5.0f;

namespace {
constexpr uint32_t kOscillatorFreqHz = 27000000;
constexpr float kServoPwmFreqHz = 50.0f;

constexpr float kNeutralHeightMm = 280.0f;
constexpr float kNeutralX = 0.0f;
constexpr float kNeutralY = 0.0f;
// IK() assumes +Z is downward from the hip pivot, so reducing the magnitude
// of Z lifts the foot toward the body. We use a neutral "stand" height and
// a closer pose for a compact STOW configuration.
constexpr float kNeutralZ = kNeutralHeightMm;
constexpr uint32_t kControlIntervalMs = 20;
constexpr float kRampSpeedMmPerSec = 120.0f;

constexpr float kBodyCurlDeltaMm = 150.0f;  // Move 15 cm toward the body.
constexpr float kCloserPoseZ = kNeutralZ - kBodyCurlDeltaMm;
static_assert(kCloserPoseZ >= 0.0f, "Closer pose Z must stay non-negative");

constexpr float kPi = 3.14159265358979323846f;
constexpr float kDegToRad = kPi / 180.0f;

constexpr int ROLL_CH_INDEX = 0;
constexpr int PITCH_CH_INDEX = 1;
constexpr int YAW_CH_INDEX = 3;
// SB is a 3-position switch used for ride height presets.
// Adjust SB_CH_INDEX if your radio maps SB to a different CRSF channel.
constexpr int SB_CH_INDEX = 5;
constexpr int SD_CH_INDEX = 7;
constexpr int SD_ON_THRESHOLD_US = 1600;
constexpr int SD_OFF_THRESHOLD_US = 1400;
constexpr float kStickCenterUs = 1500.0f;
constexpr float kStickHalfRangeUs = 500.0f;

constexpr float kMaxRollDeg = 20.0f;
constexpr float kMaxPitchDeg = 10.0f;
constexpr float kMaxYawDeg = 25.0f;
// Balance mode can use a larger tilt range than stick-driven tilt to make
// corrective leg motion more visible.
constexpr float kBalanceMaxRollDeg = 30.0f;
constexpr float kBalanceMaxPitchDeg = 20.0f;
// In balance mode we primarily adjust per-leg Z heights to keep the body
// approximately level. These constants convert virtual roll/pitch (deg) into
// foot Z changes using the actual foot XY geometry and an overall gain.
constexpr float kBalanceMaxZOffsetMm = 80.0f;
constexpr float kBalanceZGain = 2.0f;
// Safety: if the body tilt exceeds this (in any axis), balance mode
// stops trying to correct so we don't fight a fall or extreme pose.
constexpr float kBalanceCancelDeg = 45.0f;
// Balance controller gains (proportional only for now). Values near 1.0 aim
// to roughly cancel measured tilt; tune down if the motion feels too aggressive.
constexpr float kBalanceKpRoll = 1.0f;
constexpr float kBalanceKpPitch = 1.0f;
// Small deadband around zero error so we don't hunt, but keep it tiny so
// balance corrections feel effectively "real-time".
constexpr float kBalanceDeadbandDeg = 0.25f;
// Additional smoothing on the commanded body tilt in balance mode. Set to 1.0
// so new commands are applied immediately (no extra lag).
constexpr float kBalanceOutputAlpha = 1.0f;
constexpr uint32_t kLinkLossStowDelayMs = 1000;
constexpr uint32_t kSwitchDebounceDefaultMs = 200;  // Baseline debounce for SA/SD switches.
constexpr uint32_t kStandCommandHoldMs = 250;        // Additional guard before moving legs when stand toggles.
constexpr uint32_t kTiltToggleDebounceMs = 300;      // Hold tilt candidate before entering/exiting tilt.
constexpr bool kDebugLoggingEnabled = false;
constexpr bool kBalanceDebugLoggingEnabled = false;

// Ride height configuration (stand-only, 3 presets driven by SB).
// "High" is the default neutral stand height; "Medium" and "Low"
// bring the feet closer to the body (smaller Z in IK frame).
enum RideHeightPreset : uint8_t { RIDE_HIGH = 0, RIDE_MEDIUM = 1, RIDE_LOW = 2 };

// High-level body mode. This is the top-level "menu" state that we will
// extend as more behaviors are added (gaits, diagnostics, etc.).
enum BodyMode : uint8_t {
  BODY_STOW = 0,
  BODY_STAND = 1,
  BODY_TILT = 2,
  BODY_BALANCE = 3,
};

// Microsecond bands for SB positions (up / mid / down).
// These values assume ~1000 us = switch fully up, ~1500 us = middle,
// ~2000 us = fully down. Tweak if your radio outputs different ranges.
constexpr int SB_UPPER_POS_MAX_US = 1200;
constexpr int SB_LOWER_POS_MIN_US = 1800;

// Offsets from kNeutralZ (mm) for each ride height preset.
// Positive values move the feet further from the body; negative values
// move them closer. Keep results >= 0 to stay within IK assumptions.
constexpr float kRideHeightOffsetHighMm = 0.0f;     // SB up  : default stand height.
constexpr float kRideHeightOffsetLowMm = -100.0f;   // SB down: much closer to the body.
constexpr float kRideHeightOffsetMediumMm =
    0.5f * (kRideHeightOffsetHighMm + kRideHeightOffsetLowMm);  // SB mid : halfway between.

constexpr float kRideHeightOffsetsMm[3] = {
    kRideHeightOffsetHighMm,
    kRideHeightOffsetMediumMm,
    kRideHeightOffsetLowMm,
};

static_assert((kNeutralZ + kRideHeightOffsetLowMm) >= 0.0f,
              "Lowest ride height must keep leg Z non-negative");

using MoveLegFn = void (*)(Adafruit_PWMServoDriver &, float, float, float);

constexpr MoveLegFn kMoveLegFns[kLegCount] = {
    moveLegFL,
    moveLegFR,
    moveLegBL,
    moveLegBR,
};

// Nominal foot positions in the body/world frame when the body is level.
// Used by the balance controller to compute per-leg Z corrections that
// keep the body plane level while feet remain at fixed XY.
constexpr float kFootPosXBody[kLegCount] = {
    +BODY_HALF_LENGTH_X + FOOT_BACK_OFFSET_X,  // FL
    +BODY_HALF_LENGTH_X + FOOT_BACK_OFFSET_X,  // FR
    -BODY_HALF_LENGTH_X + FOOT_BACK_OFFSET_X,  // BL
    -BODY_HALF_LENGTH_X + FOOT_BACK_OFFSET_X   // BR
};

constexpr float kFootPosYBody[kLegCount] = {
    +FOOT_OUT_OFFSET_Y,   // FL
    -FOOT_OUT_OFFSET_Y,   // FR
    +FOOT_OUT_OFFSET_Y,   // BL
    -FOOT_OUT_OFFSET_Y    // BR
};

bool sdCommandActive = false;
RideHeightPreset currentRidePreset = RIDE_HIGH;

// Unified "menu" view of the robot's state based purely on RC inputs and
// link/failsafe information. The control loop consumes this instead of
// talking directly to raw switches.
struct MenuState {
  BodyMode mode;
  RideHeightPreset rideHeight;
  bool linkAlive;
  bool failsafeActive;
};

// Reference orientation captured when entering balance mode so the robot
// does not "snap" to level on entry. We cancel deviations relative to this.
float balanceRefRollDeg = 0.0f;
float balanceRefPitchDeg = 0.0f;
bool balanceRefValid = false;
// Filtered body tilt commands used in balance mode to further suppress
// oscillations and jerkiness.
float balanceRollCmdFilt = 0.0f;
float balancePitchCmdFilt = 0.0f;

float normalizeChannel(int chValueUs) {
  const float normalized = (static_cast<float>(chValueUs) - kStickCenterUs) / kStickHalfRangeUs;
  return constrain(normalized, -1.0f, 1.0f);
}

void logDebugState(uint32_t now,
                   bool linkAlive,
                   bool standCommand,
                   bool standPoseReady,
                   bool sdDown,
                   bool tiltCandidateRaw,
                   bool tiltCandidateFiltered,
                   bool tiltActive) {
  if (!kDebugLoggingEnabled) {
    return;
  }

  static uint32_t lastLogMs = 0;
  static bool firstLog = true;
  constexpr uint32_t kLogIntervalMs = 100;
  if (!firstLog && (now - lastLogMs) < kLogIntervalMs) {
    return;
  }
  firstLog = false;
  lastLogMs = now;

  const int saUs = ch_us[SA_CH_INDEX];
  const int sdUs = ch_us[SD_CH_INDEX];
  const int rollUs = ch_us[ROLL_CH_INDEX];
  const int pitchUs = ch_us[PITCH_CH_INDEX];
  const int yawUs = ch_us[YAW_CH_INDEX];

  const float rollNorm = normalizeChannel(rollUs);
  const float pitchNorm = normalizeChannel(pitchUs);
  const float yawNorm = normalizeChannel(yawUs);

  const float rollDeg = rollNorm * kMaxRollDeg;
  const float pitchDeg = pitchNorm * kMaxPitchDeg;
  const float yawDeg = yawNorm * kMaxYawDeg;

  Serial.printf(
      "DBG t=%lu link=%d lastCrsf=%lu standCmd=%d poseReady=%d standState=%d sdDown=%d tiltCandRaw=%d "
      "tiltCandFilt=%d tiltActive=%d targetZ=%.1f | SA=%d SD=%d roll=%d pitch=%d yaw=%d | rollNorm=%.2f "
      "pitchNorm=%.2f yawNorm=%.2f | rollDeg=%.1f pitchDeg=%.1f yawDeg=%.1f | poseZ=%.1f | "
      "imuOk=%d axG=%.3f ayG=%.3f azG=%.3f gxDps=%.1f gyDps=%.1f gzDps=%.1f\n",
      static_cast<unsigned long>(now),
      linkAlive ? 1 : 0,
      static_cast<unsigned long>(lastCrsfMs),
      standCommand ? 1 : 0,
      standPoseReady ? 1 : 0,
      static_cast<int>(standState),
      sdDown ? 1 : 0,
      tiltCandidateRaw ? 1 : 0,
      tiltCandidateFiltered ? 1 : 0,
      tiltActive ? 1 : 0,
      currentTargetZ,
      saUs,
      sdUs,
      rollUs,
      pitchUs,
      yawUs,
      rollNorm,
      pitchNorm,
      yawNorm,
      rollDeg,
      pitchDeg,
      yawDeg,
      lastPoseZ,
      gImuState.online ? 1 : 0,
      gImuState.ax_g_filt,
      gImuState.ay_g_filt,
      gImuState.az_g_filt,
      gImuState.gx_dps_filt,
      gImuState.gy_dps_filt,
      gImuState.gz_dps_filt);
}

void moveAllLegs(Adafruit_PWMServoDriver &driver, float x, float y, float z) {
  for (int i = 0; i < kLegCount; ++i) {
    kMoveLegFns[i](driver, x, y, z);
  }
}

struct SwitchDebounceState {
  bool pending = false;
  uint32_t pendingSince = 0;
  bool initialized = false;
};

bool applySwitchDebounce(bool currentState,
                         bool desiredState,
                         uint32_t now,
                         SwitchDebounceState *state,
                         uint32_t debounceMs) {
  if (!state->initialized) {
    state->pending = currentState;
    state->pendingSince = now;
    state->initialized = true;
  }

  if (desiredState == currentState) {
    state->pending = desiredState;
    state->pendingSince = now;
    return currentState;
  }

  if (desiredState != state->pending) {
    state->pending = desiredState;
    state->pendingSince = now;
    return currentState;
  }

  if ((now - state->pendingSince) >= debounceMs) {
    return desiredState;
  }
  
  return currentState;
}

// Forward declarations for switch handling helpers used in the menu layer.
bool updateStandCommand(bool standActive, uint32_t now);
bool updateSdCommand(bool sdActive, bool controlsEnabled, uint32_t now);

RideHeightPreset detectRideHeightPresetFromSbUs(int sbValueUs) {
  if (sbValueUs <= SB_UPPER_POS_MAX_US) {
    return RIDE_HIGH;
  }
  if (sbValueUs >= SB_LOWER_POS_MIN_US) {
    return RIDE_LOW;
  }
  return RIDE_MEDIUM;
}

RideHeightPreset readRideHeightPreset() {
  const int sbValueUs = ch_us[SB_CH_INDEX];
  return detectRideHeightPresetFromSbUs(sbValueUs);
}

float computeStandTargetZForPreset(RideHeightPreset preset) {
  const int index = static_cast<int>(preset);
  const float offset = kRideHeightOffsetsMm[index];
  const float candidate = kNeutralZ + offset;
  return (candidate >= 0.0f) ? candidate : 0.0f;
}

// Raw RC -> menu inputs -------------------------------------------------
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
void loop() {
  static uint32_t lastControlMs = 0;
  static uint32_t lastLinkAliveMs = 0;
  static bool failsafeActive = true;
  static SwitchDebounceState standModeDebounce;
  static SwitchDebounceState tiltDebounce;

  const uint32_t now = millis();
  processCrsfFrames(now);
  // Refresh IMU sample; failures simply leave the previous values.
  (void)imuReadSample();

  // 1) Read current RC "menu inputs" (switches, link status).
  const MenuInputs inputs = readMenuInputs(now, &lastLinkAliveMs, &failsafeActive);
  menuState.linkAlive = inputs.haveLink;
  menuState.failsafeActive = inputs.failsafeActive;

  // 2) Update the high-level body mode (stow / stand / tilt) with existing
  //    debouncing semantics, but represented as a single menuState.mode.
  const bool desiredStandCommand = inputs.standRequested;
  const bool filteredStandCommand =
      applySwitchDebounce(menuState.mode != BODY_STOW,
                          desiredStandCommand,
                          now,
                          &standModeDebounce,
                          kStandCommandHoldMs);

  BodyMode previousMode = menuState.mode;
  if (!filteredStandCommand || inputs.failsafeActive) {
    // For safety, force tilt mode off immediately when stowing or entering
    // failsafe so we do not continue applying tilt poses while ramping down.
    if (tiltModeActive) {
      exitTiltMode();
    }
    menuState.mode = BODY_STOW;
  } else {
    // Stand is requested; tilt may override below if allowed.
    menuState.mode = BODY_STAND;
  }

  // 3) Ride height preset is always taken from SB when stand is requested;
  //    stow ignores ride height and uses the compact pose.
  if (menuState.mode == BODY_STAND || menuState.mode == BODY_TILT || menuState.mode == BODY_BALANCE) {
    if (inputs.rideRequested != currentRidePreset) {
      currentRidePreset = inputs.rideRequested;
      Serial.printf("Ride height preset=%d SB=%d\n",
                    static_cast<int>(currentRidePreset),
                    ch_us[SB_CH_INDEX]);
    }
    menuState.rideHeight = currentRidePreset;
  } else {
    menuState.rideHeight = RIDE_HIGH;  // default; ignored in actual stow pose.
  }

  // 4) Compute the current Z target from the menu state.
  if (menuState.mode == BODY_STOW) {
    currentTargetZ = kCloserPoseZ;
  } else {
    currentTargetZ = computeStandTargetZForPreset(menuState.rideHeight);
  }
  zRamp.move(currentTargetZ);

  // Maintain legacy standState for any existing debug/logic that still uses it.
  standState = (menuState.mode == BODY_STOW) ? STOW : STAND;

  // 5) Tilt candidate: entering tilt requires the pose to be "ready" at the
  //    chosen height, but once in tilt we keep it latched as long as the
  //    stand command and tilt switch remain active. This avoids dropping out
  //    of tilt while ride height ramps between presets.
  const bool standPoseReady =
      (menuState.mode != BODY_STOW) &&
      (fabsf(lastPoseZ - currentTargetZ) <= kStandPoseToleranceMm);

  bool desiredTiltActive = false;
  if (tiltModeActive) {
    // Already in tilt: keep it as long as we are effectively "standing"
    // and the tilt switch is held (no pose-ready requirement during ramps).
    desiredTiltActive = (standState == STAND) && inputs.tiltSwitchDown && !inputs.failsafeActive;
  } else {
    // Entering tilt: require pose ready at the selected ride height so we
    // don't tilt while legs are still moving into position.
    desiredTiltActive =
        (standState == STAND) && inputs.tiltSwitchDown && standPoseReady && !inputs.failsafeActive;
  }

  const bool tiltCandidateRaw = desiredTiltActive;
  const bool tiltCandidateFiltered =
      applySwitchDebounce(tiltModeActive, tiltCandidateRaw, now, &tiltDebounce, kTiltToggleDebounceMs);
  if (tiltCandidateFiltered && !tiltModeActive) {
    enterTiltMode();
  } else if (!tiltCandidateFiltered && tiltModeActive) {
    exitTiltMode();
  }
  menuState.mode = tiltModeActive ? BODY_TILT : menuState.mode;

  // 6) Balance mode: only allowed when standing (not stow, not tilt),
  //    and when the SC switch is in the middle position.
  if (!tiltModeActive && menuState.mode == BODY_STAND && inputs.balanceRequested &&
      !inputs.failsafeActive) {
    menuState.mode = BODY_BALANCE;
  }
  // Reset balance reference when entering or leaving balance mode.
  if (previousMode != BODY_BALANCE && menuState.mode == BODY_BALANCE) {
    Serial.printf("Entering BODY_BALANCE (SC=%d, imuOk=%d)\n",
                  ch_us[SC_CH_INDEX],
                  (gImuState.online && gImuState.has_sample) ? 1 : 0);
    balanceRefValid = false;
    balanceRollCmdFilt = 0.0f;
    balancePitchCmdFilt = 0.0f;
  } else if (previousMode == BODY_BALANCE && menuState.mode != BODY_BALANCE) {
    Serial.printf("Exiting BODY_BALANCE (newMode=%d)\n", static_cast<int>(menuState.mode));
    balanceRefValid = false;
    balanceRollCmdFilt = 0.0f;
    balancePitchCmdFilt = 0.0f;
  }

  logDebugState(now,
                inputs.haveLink,
                (menuState.mode != BODY_STOW),
                standPoseReady,
                inputs.tiltSwitchDown,
                tiltCandidateRaw,
                tiltCandidateFiltered,
                tiltModeActive);

  if ((now - lastControlMs) >= kControlIntervalMs) {
    lastControlMs = now;
    const float rampZ = zRamp.update();
    lastPoseZ = rampZ;

    if (menuState.mode == BODY_TILT) {
      applyTiltPose(pca);
    } else {
      // Stand / stow / balance: use the same body-plate model as tilt mode.
      const float bodyZ = rampZ + STAND_HEIGHT_Z;
      float rollDeg = 0.0f;
      float pitchDeg = 0.0f;
      bool useBalanceZOffsets = false;
      float balanceZOffsets[kLegCount] = {0.0f, 0.0f, 0.0f, 0.0f};

      if (menuState.mode == BODY_BALANCE && gImuState.online && gImuState.has_sample) {
        // Map IMU accel (sensor frame) into body frame and estimate roll/pitch
        // from gravity. The IMU board is mounted with a 90-degree yaw offset,
        // so first form an intermediate body-like vector and then rotate it
        // -90 degrees about +Z to align with the body frame.
        const float gx_body_meas = -gImuState.az_g_filt;   // intermediate forward
        const float gy_body_meas =  gImuState.ay_g_filt;   // intermediate left
        const float gz_body_meas = -gImuState.ax_g_filt;   // intermediate up

        // Apply a -90 deg rotation about +Z: x' = y, y' = -x.
        const float gx_body =  gy_body_meas;               // forward (+X_body)
        const float gy_body = -gx_body_meas;               // left    (+Y_body)
        const float gz_body =  gz_body_meas;               // up      (+Z_body)

        const float rollRad = atan2f(gy_body, gz_body);
        const float pitchRad = atan2f(-gx_body, sqrtf(gy_body * gy_body + gz_body * gz_body));

        const float rollDegMeas = rollRad * (180.0f / kPi);
        const float pitchDegMeas = pitchRad * (180.0f / kPi);

        // If the body is tilted beyond the safety threshold, drop back to
        // normal stand (no active balancing) so we don't fight a fall.
        if ((fabsf(rollDegMeas) > kBalanceCancelDeg) ||
            (fabsf(pitchDegMeas) > kBalanceCancelDeg)) {
          if (menuState.mode == BODY_BALANCE) {
            menuState.mode = BODY_STAND;
            Serial.println("Balance mode cancelled: tilt beyond safety threshold.");
          }
        } else {
          // Capture reference at entry so we hold the current body "level"
          // and avoid a sudden snap when balance is enabled.
          if (!balanceRefValid) {
            balanceRefRollDeg = rollDegMeas;
            balanceRefPitchDeg = pitchDegMeas;
            balanceRefValid = true;
          }

          const float rollErr = rollDegMeas - balanceRefRollDeg;
          const float pitchErr = pitchDegMeas - balanceRefPitchDeg;

          // Apply a proportional correction on the deviation from the
          // reference. Use a small deadband to avoid hunting around zero.
          float rollCmd = 0.0f;
          float pitchCmd = 0.0f;
          if (fabsf(rollErr) > kBalanceDeadbandDeg) {
            rollCmd = -kBalanceKpRoll * rollErr;
          }
          if (fabsf(pitchErr) > kBalanceDeadbandDeg) {
            pitchCmd = -kBalanceKpPitch * pitchErr;
          }

          // Smooth the output commands to avoid exciting servo dynamics.
          balanceRollCmdFilt += kBalanceOutputAlpha * (rollCmd - balanceRollCmdFilt);
          balancePitchCmdFilt += kBalanceOutputAlpha * (pitchCmd - balancePitchCmdFilt);

          float rollOutDeg = balanceRollCmdFilt;
          float pitchOutDeg = balancePitchCmdFilt;
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

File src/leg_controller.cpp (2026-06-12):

#include <Arduino.h>
#include <Adafruit_PWMServoDriver.h>

#include "leg_controller.h"

#include "ik.h"

namespace {
constexpr float kServoCenterDeg = 135.0f;
constexpr float kMinPulseUs = 500.0f;
constexpr float kMaxPulseUs = 2500.0f;
constexpr float kMaxAngleDeg = 270.0f;
constexpr uint8_t kPcaChannelCount = 16;

struct ServoAngleLimit {
  float minDeg;
  float maxDeg;
};

// Per-channel hard safety limits. These were seeded from the current
// stow/stand/tilt/balance pose envelope plus margin, so a bad mode transition
// cannot command the full 0-270 degree electrical range on startup or during
// operation. Tighten these during calibration once each joint's true mechanical
// limits are known.
constexpr ServoAngleLimit kServoAngleLimits[kPcaChannelCount] = {
    {87.0f, 156.0f},   // CH0  FL hip
    {109.0f, 254.0f},  // CH1  FL upper
    {29.0f, 171.0f},   // CH2  FL lower
    {64.0f, 133.0f},   // CH3  FR hip
    {0.0f, 141.0f},    // CH4  FR upper
    {0.0f, 270.0f},    // CH5  unused
    {0.0f, 270.0f},    // CH6  unused
    {96.0f, 234.0f},   // CH7  BL upper
    {23.0f, 155.0f},   // CH8  BL lower
    {74.0f, 143.0f},   // CH9  BR hip
    {0.0f, 134.0f},    // CH10 BR upper
    {80.0f, 212.0f},   // CH11 BR lower
    {0.0f, 270.0f},    // CH12 unused
    {0.0f, 270.0f},    // CH13 unused
    {77.0f, 146.0f},   // CH14 BL hip
    {71.0f, 213.0f},   // CH15 FR lower
};

float clamp270(float angle) { return constrain(angle, 0.0f, kMaxAngleDeg); }

float applyServoSafetyLimit(uint8_t channel, float angleDegrees) {
  const float clamped = clamp270(angleDegrees);
  if (channel >= kPcaChannelCount) {
    return clamped;
  }
  const ServoAngleLimit &limit = kServoAngleLimits[channel];
  return constrain(clamped, limit.minDeg, limit.maxDeg);
}

uint16_t angleToPulse(float angleDegrees) {
  const float clamped = clamp270(angleDegrees);
  const float ratio = clamped / kMaxAngleDeg;
  const float microseconds = kMinPulseUs + (kMaxPulseUs - kMinPulseUs) * ratio;
  return static_cast<uint16_t>(microseconds);
}

void write270(Adafruit_PWMServoDriver &driver, uint8_t channel, float angleDegrees) {
  driver.writeMicroseconds(channel, angleToPulse(applyServoSafetyLimit(channel, angleDegrees)));
}

// Leg channel assignments:
// FL: hip=0,  upper=1,  lower=2
// FR: hip=3,  upper=4,  lower=15
// BL: hip=14, upper=7,  lower=8
// BR: hip=9,  upper=10, lower=11

// Right legs use +1 directions; left legs share the same hip direction, but mirror upper/lower.
const LegConfig FR_leg{
    "FR",                // name
    3,                   // hipChannel
    4,                   // upperChannel
    15,                  // lowerChannel
    FR_HIP_TRIM_DEG,     // hipTrimDeg
    FR_UPPER_TRIM_DEG,   // upperTrimDeg
    FR_LOWER_TRIM_DEG,   // lowerTrimDeg
    +1,                  // hipDir
    +1,                  // upperDir
    +1,                  // lowerDir
    0.0f,                // hx
    0.0f};               // hy

const LegConfig BR_leg{
    "BR",                // name
    9,                   // hipChannel
    10,                  // upperChannel
    11,                  // lowerChannel
    BR_HIP_TRIM_DEG,     // hipTrimDeg
    BR_UPPER_TRIM_DEG,   // upperTrimDeg
    BR_LOWER_TRIM_DEG,   // lowerTrimDeg
    +1,                  // hipDir
    +1,                  // upperDir
    +1,                  // lowerDir
    0.0f,                // hx
    0.0f};               // hy

const LegConfig FL_leg{
    "FL",                // name
    0,                   // hipChannel
    1,                   // upperChannel
    2,                   // lowerChannel
    FL_HIP_TRIM_DEG,     // hipTrimDeg
    FL_UPPER_TRIM_DEG,   // upperTrimDeg
    FL_LOWER_TRIM_DEG,   // lowerTrimDeg
    +1,                  // hipDir (all hips oriented the same way in hardware)
    -1,                  // upperDir
    -1,                  // lowerDir
    0.0f,                // hx
    0.0f};               // hy

const LegConfig BL_leg{
    "BL",                // name
    14,                  // hipChannel
    7,                   // upperChannel
    8,                   // lowerChannel
    BL_HIP_TRIM_DEG,     // hipTrimDeg
    BL_UPPER_TRIM_DEG,   // upperTrimDeg
    BL_LOWER_TRIM_DEG,   // lowerTrimDeg
    +1,                  // hipDir (all hips oriented the same way in hardware)
    -1,                  // upperDir
    -1,                  // lowerDir
    0.0f,                // hx
    0.0f};               // hy
}  // namespace

void moveLeg(const LegConfig &leg, Adafruit_PWMServoDriver &driver, float x, float y, float z) {
  float theta1 = 0.0f;
  float theta2 = 0.0f;
  float theta3 = 0.0f;
  IK(x, y, z, &theta1, &theta2, &theta3);

  const float hipAngle = kServoCenterDeg + leg.hipTrimDeg + static_cast<float>(leg.hipDir) * theta1;
  const float upperAngle = kServoCenterDeg + leg.upperTrimDeg + static_cast<float>(leg.upperDir) * theta2;
  const float lowerAngle = kServoCenterDeg + leg.lowerTrimDeg + static_cast<float>(leg.lowerDir) * theta3;

  write270(driver, leg.hipChannel, hipAngle);
  write270(driver, leg.upperChannel, upperAngle);
  write270(driver, leg.lowerChannel, lowerAngle);
}

// Wrappers per leg
void moveLegFR(Adafruit_PWMServoDriver &driver, float x, float y, float z) { moveLeg(FR_leg, driver, x, y, z); }
void moveLegFL(Adafruit_PWMServoDriver &driver, float x, float y, float z) { moveLeg(FL_leg, driver, x, y, z); }
void moveLegBR(Adafruit_PWMServoDriver &driver, float x, float y, float z) { moveLeg(BR_leg, driver, x, y, z); }
void moveLegBL(Adafruit_PWMServoDriver &driver, float x, float y, float z) { moveLeg(BL_leg, driver, x, y, z); }

// Stub: future body pose handling (keep feet fixed, move body)
void setBodyPose(const BodyPose & /*pose*/, Adafruit_PWMServoDriver & /*driver*/) {
  // Intentionally empty for now.
}

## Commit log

2026-06-12 Rename project to CarbonQuadruped ESP32
2026-06-12 Document CRSF receiver PCB modification
2026-06-12 Harden CRSF failsafe and servo limits
    [leg_controller.cpp, main.cpp]
2026-06-12 Add Domino CAD exports and design notes
    [BL.step, BR.step, Body.step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]
2026-06-13 Add Domino PCB V1.1B Gerber package
2026-06-13 Replace PCB photos with Domino board images
2026-06-13 Refresh Domino PCB Gerbers and screenshots
2026-06-13 Use fresh Domino PCB screenshot paths
2026-06-14 Add Isaac bring-up notes and URDF topology report
    [DOM_P_1.stl, DOM_P__10__1.stl, DOM_P__11__1.stl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]
2026-06-14 Add Isaac URDF import smoke test
2026-06-14 Add Isaac one-leg prototype
    [domino_one_leg_clean.urdf]
2026-06-14 Add Isaac one-leg runtime sweep
2026-06-14 Add Isaac pin-linkage prototype
2026-06-14 Add CAD-derived Domino linkage test
2026-06-15 Add combined Domino leg linkage test
2026-06-15 Add Domino linkage calibration reporting
2026-06-15 Add four-leg Domino CAD linkage simulation
2026-06-15 Add independent all-leg linkage calibration
2026-06-15 Add twelve-actuator Domino linkage mode
2026-06-15 Add shared-body twelve-actuator linkage gate
2026-06-15 Add clean twelve-DoF quadruped Isaac prototype
    [domino_quadruped_clean.urdf]
2026-06-16 Add Domino CAD linkage contract check
2026-06-16 Add floating CAD linkage contact smoke
2026-06-16 Add floating CAD policy reset smoke
2026-07-25 Add reproducible Domino CAD policy training
2026-07-25 Add gated velocity locomotion training
2026-07-27 Add gated locomotion curriculum and Domino materials
2026-07-27 Use high-contrast Domino prototype palette
2026-07-27 Refine Domino prototype materials
2026-07-27 Make Domino leg assemblies black
2026-07-28 Benchmark and select Domino training devices
2026-07-28 Stage Domino gait validation progressively
2026-08-08 Checkpoint standalone gait before anti-slip tuning
    [main.cpp]
2026-08-08 Reduce forward gait scrub and lateral drift
    [main.cpp]
2026-08-13 Add guided LIVE servo calibration
2026-08-13 Add LIVE command-chain diagnostics
2026-08-13 Add floating calibration preview toggle
2026-08-13 Add fail-closed ESP32 LIVE endpoint
    [leg_controller.cpp, main.cpp]
2026-08-13 Persist validated servo calibration profiles
2026-08-21 Add wireless LIVE link and servo channel mapping
2026-08-21 Add current Virtual Lab usage media
2026-08-21 Add optional measured power telemetry
2026-08-21 Add staged LIVE hardware bring-up guide
2026-08-21 Show camera navball in LIVE workspace
2026-08-21 Add armed glow and LIVE joint inspector
2026-08-21 Dock camera control in LIVE preview panels
2026-08-21 Ground LIVE gait preview from CAD feet
2026-08-21 Fix LIVE view camera and inspector ownership
2026-08-21 Run camera navigation updates in LIVE views
2026-08-22 Expose calibrated servo output telemetry
2026-08-22 Record calibrated servo PWM traces
2026-08-22 Add latched low-voltage fault recovery
2026-08-22 Add guarded calibration default restore
2026-08-26 fix: make GPS track status explicit
2026-08-26 feat: show LiDAR clearance on route map
2026-08-26 feat: surface live camera telemetry
2026-08-26 fix: contain live sensor layouts
2026-08-27 feat: add device location route origin
2026-08-27 fix: clarify camera stream retry flow
2026-08-27 feat: add map wheel zoom controls
2026-08-27 fix: contain live sensor typography
2026-08-27 feat: add camera stream reset control
2026-08-27 feat: show camera frame health
2026-08-27 fix: keep live camera health state current
2026-08-27 feat: include camera health in diagnostics
2026-08-27 fix: remove redundant camera refresh loop
2026-08-27 fix: tighten live compare banner
2026-08-27 fix: theme live camera panel
2026-08-27 fix: unify live tab title rails
2026-09-28 release: Domino Studio v0.2.26 with calibration
2026-10-12 fix: keep robot calibration, report its source, refresh README (firmware 0.8.16)
    Firmware
    - Store calibration as an explicit, versioned, checksummed 212-byte record
    (active2) instead of a raw struct dump, with a backup copy (backup2) kept
    on every save. Boot order: active2, backup2, legacy 0.8.15 blob, defaults.
    - Report where the active profile came from (nvs, nvs-backup, nvs-legacy,
    default-empty, default-fallback + reason) in robot-hello, profile
    readbacks and the boot log.
    Studio
    - Warn with a banner when the robot is running default calibration.
    - Never overwrite a saved browser profile with robot defaults; restore it
    (or the last profile read from a healthy robot) as an unsa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
2026-10-12 docs: lead README with the physical robot, then electronics, CAD and Studio
2026-10-13 fix: let calibration saves skip bench mode, keep drafts, end bench on disconnect (Studio 0.3.3, firmware 0.8.17)
    - Saving a profile no longer requires bench mode (flash write only, outputs off first).
    - Unsaved imported/edited calibration drafts persist across Studio restarts.
    - Disconnecting the engineering session sends the robot a bench-mode exit.
    - Clear import message; tests for reconnect and save-without-bench.
2026-10-13 release: Domino Quadruped Studio v0.3.10 (firmware 0.8.18), restoring the 0.3.8 line
    Studio 0.3.2/0.3.3/0.3.9 were built from an older code line by mistake. This restores the
    0.3.8 work (calibration audit fixes, help, notifications, connection feedback, firmware 0.8.18)
    on top of main, keeping the README, license, CI Electron fix and release docs.
2026-10-13 release: Domino Quadruped Studio v0.4.0 (firmware 0.8.19)
    Built on the 0.3.10 line (0.3.8 calibration audit fixes, firmware 0.8.18) plus:
    - Robot reports where its calibration profile came from (nvs, nvs-backup, nvs-legacy,
    default-empty, default-fallback + reason) in hello and profile readbacks.
    - Versioned, checksummed calibration record with an automatic backup; reads the old raw blob.
    - Studio warns when the robot runs defaults and never overwrites a saved browser profile with them.
    - Keep an unreadable stored browser profile instead of deleting it.
2026-10-13 docs: real bill of materials, filled as-built record, skimmable Virtual Lab and route planner pages
    - New docs/bill-of-materials.md with the actual parts (ESP32-DevKitC, PCA9685, SZBK07, KY-019,
    SpeedyBee Nano ELRS receiver, servos, 4S packs) and the servo channel map.
    - Replace the empty MEASURE/VERIFY template with a filled as-built record.
    - Split the 40 KB virtual-lab.md into a short overview with tables plus docs/route-planner.md.
2026-10-13 fix: default calibration is the verified robot profile, and sends list what they change (Studio 0.4.1, firmware 0.8.20)
    The compiled and Studio defaults were the plain CAD basis (zero trims, left hips not inverted).
    Restore defaults, a from-scratch profile, or a fallback therefore dropped the inverted left hips
    and the horn trims, and sending that profile broke roll and tilt. Channels were not mixed up.
    - Firmware and Studio now default to the verified profile (CH0/CH14 inverted + trims); a test
    keeps the two tables identical.
    - The send confirmation compares with the robot's profile and lists changes, with direction and
    output-channel changes in red.
    - Fallback banner now says the robo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
2026-10-13 fix: HOTFIX 0.4.2 - CONFIRM & SEND did nothing; app-wide audit fixes (Studio 0.4.2, firmware 0.8.21)
    Hotfix
    - The save dialog is modal, so the reason a send was refused was written behind it and the button
    silently did nothing. The reason is now shown in the dialog and the button stays disabled.
    - Firmware 0.8.21+ saves the profile without bench mode (flash write only, outputs off); Studio and the
    companion negotiate this per firmware version. Older firmware still requires bench mode.
    Audit fixes
    - SIL walking scenario passes again: its timeline now allows the firmware's careful->trot landing handoff.
    - Stop polling runtime/state.json ~43x/s when the simulator is down (backoff, pause wh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
2026-10-16 cad: add v6 robot STEP downloads and generative bracket FEA package
    - cad/step/latest: full v6 robot (body_v6), right and left leg modules,
    and the body frame as STEP for download.
    - cad/fea_generative_bracket: linear static FEA of the generative knee
    bracket under the Quadruped Studio pin-reaction load cases, with the
    solver and render scripts, load inputs, geometry, results and plots.
    Current bracket peaks at 1.78 MPa (SF ~28 in-layer, ~14 inter-layer).
    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
2026-10-16 docs: add knee bracket stress analysis section to the README
2026-10-16 docs: lead the bracket analysis with the bolt-hole bearing limit, not the body safety factor
